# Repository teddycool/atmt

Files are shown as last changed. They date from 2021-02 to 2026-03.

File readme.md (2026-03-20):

# An Autonomous Toy Monster Truck

This project is undergoing a huge change and will be updated with new information and code. The project is now being prepared for ScaniaHack 2026 and use the progress we made in 2024 and 2025 as a starting point.

The old branches are still available and can be used for reference but the scaniahack2026 branch will be uppdated and restructured and then merged back to main when the hack is over.

## Repo Overview
The goal with this repo was to make an 'autonomous' toy-monster-truck, using my own electronic design and software for the control system. To get a head-start I used a cheap radio-controlled toy-truck and replaced the radio-control-pcb with my own designed control-system-pcb.

The 'brain' of the truck is an ESP32-wroom 8MB and the sensors used are ultrasonic distance-sensors and acc/gyro/compass. This design was made to be simple and easy to both understand and replicate. I hope it will be a source of inspiration and give ideas for improvements. 

I now have 2 of these trucks and I am planning to use them for ScaniaHack 2026.

This branch (ScaniaHack2026) is 'cleaned-up' and updated with alot of informatiom and will focus on the work at this years ScaniaHack 19th and 20th of March.

## ScaniaHack 2026 goal (only software)
We will use the 2 toy-trucks to build a cooperative, learning-based autonomous 'racing' system. The trucks will explore, map, optimize speed, and avoid obstacles on a simple bounded track.

By using the data collected from the trucks, we will implement a learning-based algorithm to optimize the racing strategy. The trucks will communicate with a backend server to share information about the track and their performance. The backend server(s) will also be responsible for storing the data and providing insights into the performance of the trucks.

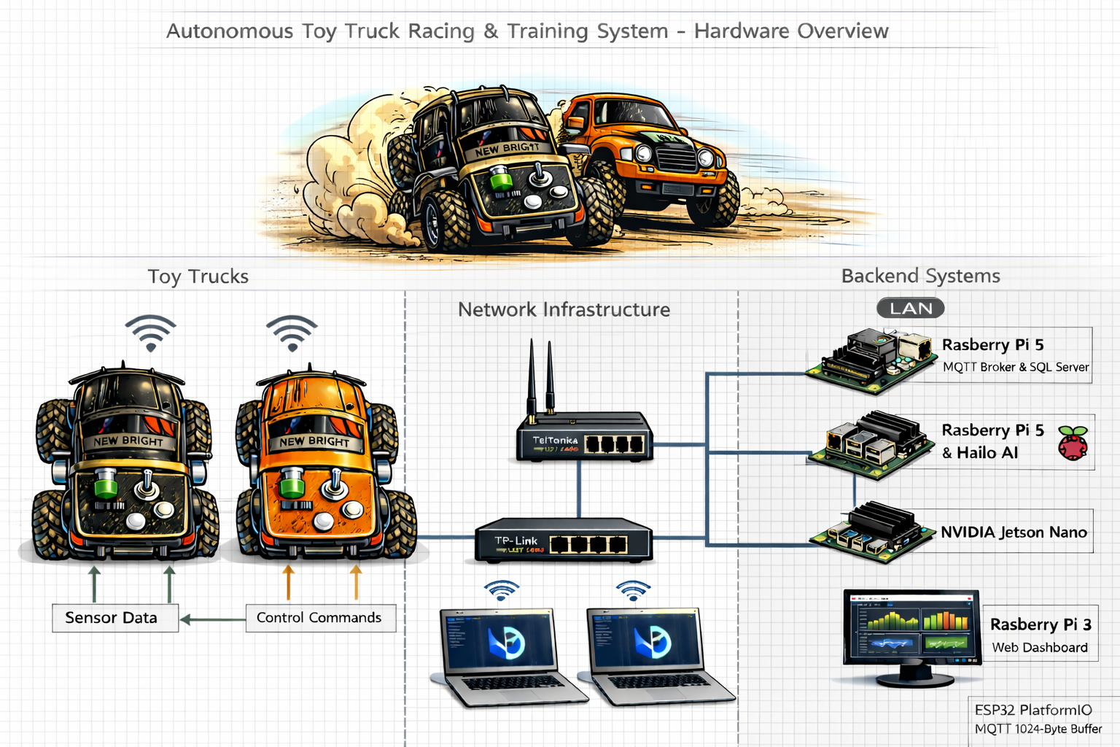
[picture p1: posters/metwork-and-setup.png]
The ScaniaHack 2026 setup


Link to the complete project description for ScaniaHack 2026: [ScaniaHack 2026 project description](ESP32_Truck_Hackathon_Project_Description.md)

### The simple track
Built with 45x70mm wood-planks, the track is a closed loop with angled corners and a clear start/finish line (the narrowest part).

### What we have
* 2 working toy-trucks with the same hardware setup and with 'ota' capabilities
* Backend servers for data collection, analysis and training of the learning-based algorithm
* A simple track for testing and racing
* Software components for sensors, basic control, data collection, and communication with the backend servers
* A dedicated server showing a dashboard with the telemetry

### What we need to implement
* An updated control-loop that 'explores' the track
* A backend 'training' that use the telemetry data to figure out the track geometry
* An updated control-loop that uses the information from backend to 'race' the track and improve laptimes

---

## How to contribute (not only code or ScaniaHack 2026) 

(More details for the git-magic in the wiki)

* Fork this repo from main and do your thing in a feature-branch from this fork on your own github-account 
* When done, make a pull-request back to main and describe your changes in the pull-request
* Try to keep one feature or bug-fix per pull-request to make the merging easier
* If you have any questions or need help, just ask me by pm, email, IRL or in the pull-request and I will try to help you out.

**Note: when working in vscode with platformio you need to open the EmbeddedSw subfolder from where you have cloned the repo, and then you can work, build and download to esp from there.**

## How to get started

[How to get started with coding](getstarted.md)

[HW schematics for reference](toy-truck/electronics/atmt-schematic-v3.pdf)

[Used hardware](toy-truck/electronics/hardware.md)

## Documentation

* [**Complete Project Description**](ESP32_Truck_Hackathon_Project_Description.md) - Comprehensive ScaniaHack 2026 project overview
* [Arduino OTA Process Guide](arduino-ota-process.md) - Complete guide for wireless firmware updates
* [Kalman Filter Implementation](kalman_filter.md) - Sensor fusion and filtering algorithms
* [EmbeddedSw Documentation](EmbeddedSw/README.md) - Main firmware documentation
* [Dashboard Setup](truck_telemetry_dashboard/README.md) - Real-time telemetry dashboard
* [Remote Control Guide](remote/README.md) - Manual and AI-based remote control

## Repo layout:

Current repository structure and components:

**Main Documentation (Root Level):**
* **ESP32_Truck_Hackathon_Project_Description.md** - Complete ScaniaHack 2026 project overview
* **arduino-ota-process.md** - Complete guide for Over-The-Air firmware updates
* **kalman_filter.md** - Implementation guide for sensor fusion algorithms

**Core Directories:**
* **EmbeddedSw/** - Main ESP32 firmware (PlatformIO project) - open this folder in VS Code to work with the truck control code
* **toy-truck/** - Hardware design and mechanical components
  * **electronics/** - PCB schematics (KiCAD), component lists, and hardware documentation
  * **Chassi-prep/** - CAD models and 3D printables for truck modifications
* **truck_telemetry_dashboard/** - Real-time web dashboard for monitoring truck telemetry data
* **remote/** - Manual control scripts and computer vision detection for remote operation
* **www/** - Backend web server components
  * PHP scripts for data logging and viewing
  * Database interaction utilities

**Supporting Materials:**
* **doc/** - Project documentation, system diagrams, and reference images
  * Architecture diagrams and project planning materials
  * Phase 1 mapping documentation
  * Historical work descriptions and conversion notes
* **posters/** - Visual presentation materials and setup diagrams for ScaniaHack 2026

---

## Other uses of this repo:
It is possible to use my PCB-design for an other type of vehicle or use the schematics and build any other sort of control-board. The ESP32 is a very versatile microcontroller and can be used for many different applications.

## Good links to get started with ESP32

* [Random Nerd Tutorials](https://randomnerdtutorials.com)
* [Espressif Resources](https://www.espressif.com/en/products/socs/esp32/resources)
* [ESP-IDF Programming Guide](https://docs.espressif.com/projects/esp-idf/en/latest/esp32/get-started/index.html)
* [Arduino Guide for ESP32](https://www.arduino.cc/en/Guide/ESP32)

## Connect and download to the ESP32

Connecting and downloading to the ESP might be a nightmare some times. Usually it goes well but when it starts to bug it can go on forever. However, you are not alone, google will help out when you search for your error message. 

Sometimes it works better if you power the pcb from the usb-port using a 3.3V type of FTD like FTDI1232 set to 3.3V. In this case the power from the batteries needs to be off or you might destroy the circuit. **Always leave battery-power off when using power from the programming interface**.

## Errata HW version 3 (important stuff)

* Some connections where missing in the first version of the schematics, like the connection between the B+ and the diode in the voltage-regulator. This is now fixed in the schematics and the pcb-layout for version 3.1

## Errata HW version 2 (important stuff)

* To keep the ESP safe on the io-side I am using rechargable batteries summing up to 3.6 volts which works just fine, but with alkalines you will probably get like 4.6 or 4.7 volts with fresh batteries which might damage the ESP32 io. Don't use those... 
* In the schematics I used a 1N4148 diode for reversed polarity protection but this was NOT a good choice. This can be left out completely or replaced by a schottky type of diode with a low voltage-drop.

## Starting material from Biltema's toy-department

Unfurthunatly this specific model is not sold anymore at Biltema but there are many other models at Biltema or elsewhere that can be used for this project. The most important thing is that the chassi is big enough to fit the new electronics and that the wheels are big enough to handle the terrain where you want to drive.

## Designing a new PCB formfactor

You can of course also design a new PCB formfactor from the schematics provided. The KiCAD files in the `toy-truck/electronics` directory include all the necessary components and connections. Feel free to modify the layout to better fit your specific needs or to improve the design. If you come up with a better design, please share it with the community by making a pull-request.

[Schematics for reference](toy-truck/electronics/atmt-schematic-v3.pdf)

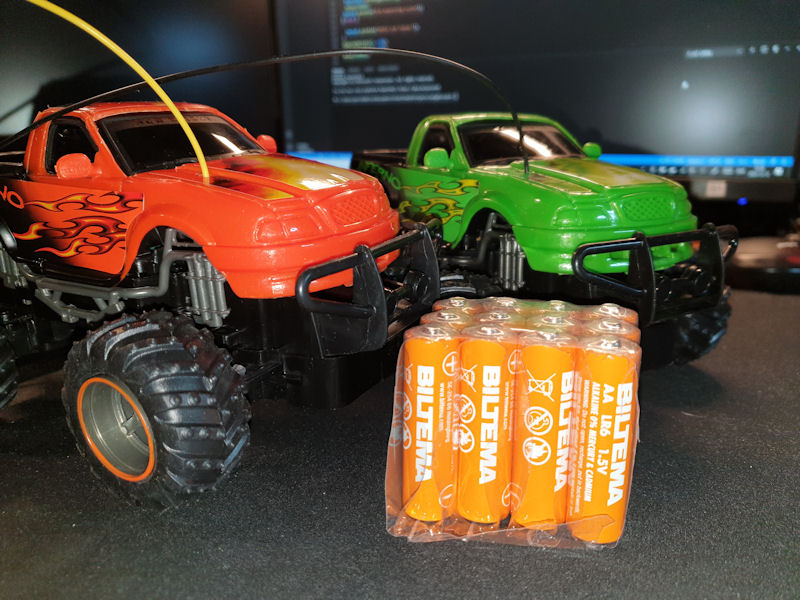
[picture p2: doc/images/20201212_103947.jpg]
Starters from Biltema toy-department


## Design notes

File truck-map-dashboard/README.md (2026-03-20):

# Truck Mapping Dashboard

A real-time web-based dashboard for mapping and tracking an autonomous toy truck. This is **Step 1** of a mapping system that receives telemetry from a truck and creates a live 2D occupancy grid map.

## Features

- **Real-time telemetry processing**: Receives truck sensor data via HTTP POST
- **Live pose estimation**: Tracks truck position and heading using motion model
- **Occupancy grid mapping**: Creates 2D maps using ultrasonic sensor data
- **Web dashboard**: Live-updating browser interface with WebSocket
- **SQLite logging**: Stores all telemetry data for analysis
- **Test mode**: Includes telemetry simulator for testing without real hardware

## Tech Stack

- **Python 3.11+**
- **Flask** - Web framework
- **Flask-SocketIO** - Real-time communication
- **NumPy** - Numerical computation for mapping
- **Pillow** - Image rendering
- **SQLite** - Data storage
- **eventlet** - Async support

## Project Structure

```
truck-map-dashboard/
├── app.py                 # Main Flask application
├── config.py             # Configuration settings
├── requirements.txt      # Python dependencies
├── telemetry_sim.py      # Test data generator
├── README.md             # This file
├── templates/
│   └── index.html        # Web dashboard UI
├── static/
│   └── style.css         # Dashboard styling
└── core/                 # Core mapping modules
    ├── telemetry.py      # Telemetry data handling
    ├── pose.py           # Pose estimation
    ├── occupancy_grid.py # Occupancy grid mapping
    ├── renderer.py       # Map visualization
    └── database.py       # SQLite operations
```

## Quick Start

### 1. Setup Python Environment

In VS Code, open a terminal and create a virtual environment:

```bash
# Navigate to project directory
cd truck-map-dashboard

# Create virtual environment
python3 -m venv venv

# Activate virtual environment
source venv/bin/activate  # On Linux/Mac
# or
venv\Scripts\activate     # On Windows
```

### 2. Install Dependencies

```bash
pip install -r requirements.txt
```

### 3. Run the Dashboard

```bash
python app.py
```

The dashboard will start at: **http://localhost:5000**

### 4. Test with Simulator

In a new terminal (with the virtual environment activated):

```bash
python telemetry_sim.py
```

This will generate fake truck telemetry and you should see the map updating in real-time!

## Usage

### Dashboard Interface

The web dashboard shows:

- **Live Map**: Real-time occupancy grid with truck position and heading
- **Truck Status**: Current position, heading, mode, and control commands  
- **Sensor Readings**: Ultrasonic sensor values (front, back, left, right)
- **System Stats**: Packet counts, map statistics, error counts
- **Controls**: Reset map, export PNG, view debug info

### API Endpoints

- `POST /api/telemetry` - Receive telemetry data
- `GET /api/status` - Get system status
- `GET /api/map/image` - Get current map as base64 PNG
- `POST /api/map/reset` - Reset map to empty state
- `POST /api/map/export` - Export map as PNG file
- `GET /api/debug` - Get detailed debug information

### Telemetry Format

Send JSON data to `/api/telemetry` with this structure:

```json
{
  "truck_id": "8a0a8ab4",
  "seq": 3282,
  "t_ms": 1876933,
  "free_heap": 216128,
  "mode": "RECOVER",
  "ul": 199.0,
  "ur": 199.0, 
  "uf": 18.0,
  "ub": 53.2,
  "yaw_rate": 1.88,
  "gy_x": -22.95,
  "gy_y": 23.25,
  "gy_z": 246.69,
  "heading": 144.3,
  "compass": 144.3,
  "mag_x": 10.00,
  "mag_y": 11.00,
  "mag_z": -36.02,
  "acc_x": -143.58,
  "acc_y": 4390.02,
  "acc_z": 15981.24,
  "width": 398.0,
  "center_error": -0.0,
  "front_blocked": true,
  "cmd_pwm": 95,
  "cmd_steer": "LEFT"
}
```

## Configuration

Edit `config.py` to tune the mapping system:

### Motion Model
```python
SPEED_PER_PWM = 0.005       # Speed in m/s per PWM unit
MAX_SPEED_MPS = 0.5         # Maximum speed 
TURN_SPEED_FACTOR = 0.3     # Speed reduction while turning
```

### Map Settings
```python
MAP_WIDTH_M = 10.0          # Map width in meters
MAP_HEIGHT_M = 10.0         # Map height in meters  
CELL_SIZE_M = 0.05          # Resolution: 5cm per cell
```

### Sensor Model
```python
SENSOR_MAX_RANGE_CM = 180.0 # Maximum trusted range
SENSOR_MIN_RANGE_CM = 2.0   # Minimum trusted range
SENSOR_INVALID_VALUE = 199.0 # Value for "no return"
```

## How It Works

### 1. Telemetry Processing
- Validates incoming JSON packets
- Parses sensor readings and control commands
- Stores raw data in SQLite database

### 2. Pose Estimation
- Uses heading from compass/IMU as primary orientation
- Estimates forward motion from PWM commands and time
- Applies speed reductions for turning and recovery modes
- Maintains (x, y, θ) pose estimate

### 3. Occupancy Grid Mapping
- Creates 2D grid with configurable resolution (default: 5cm cells)
- Uses log-odds representation for occupancy probabilities
- For each ultrasonic sensor:
  - Traces ray from sensor to detected obstacle
  - Marks free space along ray
  - Marks endpoint as occupied (if valid reading)
- Handles sensor placement and orientation relative to truck

### 4. Visualization
- Renders occupancy grid as grayscale image
- Overlays truck position (red circle) and heading (red line)
- Shows coordinate system and scale information
- Updates in real-time via WebSocket

## Limitations (Step 1)

This is a basic mapping system with these limitations:

- **No SLAM**: No loop closure or scan matching
- **Simple motion model**: Basic PWM-to-speed conversion
- **No sensor fusion**: Relies primarily on heading sensor
- **No obstacle tracking**: Static occupancy representation
- **Limited sensor model**: Simple ray-casting model

## Next Steps

Future improvements could include:

1. **Scan matching** for improved pose accuracy
2. **Loop closure detection** for map consistency  
3. **Kalman filtering** for sensor fusion
4. **Dynamic obstacle tracking**
5. **Path planning integration**
6. **Camera data processing** with Hailo acceleration

## Troubleshooting

### Dashboard won't load
- Check if Flask app is running: `python app.py`
- Verify port 5000 is not in use
- Check browser console for JavaScript errors

### Simulator not connecting
- Ensure Flask app is running first
- Check firewall/network settings
- Verify URL in telemetry_sim.py matches Flask server

### Map not updating
- Check WebSocket connection status in browser
- Verify telemetry data format matches expected JSON
- Check browser developer tools for errors
- Look at Flask console output for error messages

### Tuning the motion model
- Adjust `SPEED_PER_PWM` in config.py based on your truck's speed
- Modify `TURN_SPEED_FACTOR` if turning behavior looks wrong
- Change `SENSOR_MAX_RANGE_CM` to match your sensor specifications

### Performance issues
- Reduce map size or increase cell size for better performance
- Lower telemetry update rate if CPU usage is high
- Check available RAM for large maps

## Development

### Adding new features
1. Core mapping logic goes in the `core/` modules
2. Web API endpoints are added to `app.py`
3. UI updates go in `templates/index.html` and `static/style.css`
4. Configuration options are defined in `config.py`

### Testing
- Use `telemetry_sim.py` for development testing
- Modify simulator parameters to test edge cases
- Export maps as PNG for visual verification
- Check debug endpoint for detailed state information

---

**Happy Mapping! 🗺️🚛**

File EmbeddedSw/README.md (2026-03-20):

# Autonomous Truck Control System

A real-time ESP32-based autonomous truck control system with sensor fusion, state machine control, and telemetry integration for warehouse/industrial navigation.

## 🚛 System Overview

This system implements an autonomous truck capable of:
- **Autonomous Navigation**: Wall-following and corridor-centering using ultrasonic sensors
- **Obstacle Avoidance**: Real-time collision detection and recovery maneuvers
- **State Management**: Robust state machine with IDLE/EXPLORE/RECOVER/STOP modes
- **Real-time Telemetry**: 1Hz MQTT telemetry with sensor data and control state
- **Remote Monitoring**: Web dashboard for live visualization and control

## 🏗️ Architecture

```
┌─────────────────┐    ┌──────────────────┐    ┌─────────────────┐
│   ESP32 Truck   │◄──►│  MQTT Broker     │◄──►│ Flask Dashboard │
│                 │    │ (192.168.2.2)    │    │ (WebSocket)     │
│ ┌─────────────┐ │    │                  │    │                 │
│ │Control Loop │ │    │ Topics:          │    │ - Live Sensors  │
│ │   1Hz       │ │    │ {chipId}/sensors │    │ - State Viz     │
│ │             │ │    │ {chipId}/control │    │ - Controls      │
│ └─────────────┘ │    │ {chipId}/config  │    │                 │
│                 │    └──────────────────┘    └─────────────────┘
│ Sensors:        │
│ - 4x Ultrasonic │
│ - MPU6050       │
│ - Magnetometer  │
│                 │
│ Actuators:      │
│ - Motor Control │
│ - Steering      │
└─────────────────┘
```

## 📁 Project Structure

```
EmbeddedSw/
├── src/
│   ├── z_main_control_loop.cpp     # Main control loop
│   ├── z_main_wifi_test.cpp        # Network connectivity test
│   ├── z_main_minimal_test.cpp     # Hardware recovery utility
│   ├── config.cpp                  # Hardware configuration
│   ├── secrets.cpp                 # WiFi credentials
│   ├── actuators/
│   │   ├── motor.cpp               # Motor PWM control
│   │   ├── steer.cpp               # Steering control
│   │   ├── neopixel.cpp            # LED indicators (optional)
│   │   └── light.cpp               # Light control (optional)
│   ├── sensors/
│   │   ├── accsensor.cpp           # MPU6050 accelerometer/gyro
│   │   ├── compass.cpp             # Magnetometer with Kalman filtering
│   │   ├── usensor.cpp             # Ultrasonic sensor array
│   │   └── kalman_filter.cpp       # Kalman filter implementation
│   ├── telemetry/
│   │   ├── mqtt.cpp                # MQTT communication
│   │   └── logger.cpp              # HTTP logging (optional)
│   └── variables/
│       └── setget.cpp              # Thread-safe global variables
├── include/                        # Header files
├── platformio.ini                  # Build configuration
└── truck_telemetry_dashboard/      # Python Flask dashboard
    ├── app.py                      # WebSocket server
    ├── templates/index.html        # Web interface
    └── requirements.txt            # Python dependencies
```

## 🎛️ Control Loop Architecture

### State Machine

The control loop operates as a finite state machine with four primary states:

```cpp
enum class Mode {
    IDLE,       // Stationary, awaiting commands
    EXPLORE,    // Active navigation with wall-following
    RECOVER,    // Obstacle avoidance maneuvers
    STOP        // Emergency stop condition
};
```

### Sensor Fusion Pipeline

#### 1. Ultrasonic Sensor Array
```cpp
struct UltrasonicReadings {
    float ul;  // Upper left  (45°)
    float ur;  // Upper right (45°) 
    float sl;  // Side left   (90°)
    float sr;  // Side right  (90°)
};
```

#### 2. IMU Processing
- **MPU6050**: Raw accelerometer (±2g) and gyroscope (±250°/s)
- **EMA Filtering**: Configurable smoothing (α = 0.1 default)
- **Compass**: HMC5883L with Kalman filtering for magnetic interference

#### 3. Feature Extraction
```cpp
struct Features {
    float width;        // Corridor width (ul + ur)
    float centerError;  // Distance from corridor center
    float frontDist;    // Minimum forward obstacle distance
    float sideDist;     // Minimum side clearance
};
```

### Control Algorithm

#### Wall-Following Logic
```cpp
// Corridor centering with configurable gains
float steerGain = 2.0f;       // Proportional steering response
float centerTarget = 0.0f;    // Desired center position
float steerCmd = steerGain * (centerTarget - centerError);
```

#### State Transitions
- **IDLE → EXPLORE**: Manual command or timer trigger
- **EXPLORE → RECOVER**: Front obstacle detected (`frontDist < stopDist`)
- **RECOVER → EXPLORE**: Clear path restored
- **ANY → STOP**: Emergency condition or manual override

#### Safety Parameters
```cpp
float stopDist = 15.0f;      // Emergency stop distance (cm)
float sideMinDist = 6.0f;    // Minimum side clearance (cm)
float maxSpeed = 150;        // Maximum motor PWM (0-255)
```

## 📡 Communication Protocol

### MQTT Topics

All topics are prefixed with unique `chipId` (ESP32 MAC-derived):

#### Telemetry (Outbound - 1Hz)
```
{chipId}/sensors
```

**Payload Structure:**
```json
{
  "truck_id": "abc123def456",
  "seq": 1234,
  "timestamp": 1734567890,
  "mode": "EXPLORE",
  "sensors": {
    "ul": 25.4, "ur": 23.8, "sl": 12.3, "sr": 15.7,
    "accX": 0.12, "accY": -0.05, "accZ": 9.81,
    "gyroZ": 2.3, "compass": 185.7
  },
  "features": {
    "width": 49.2,
    "centerError": -1.4,
    "frontDist": 45.6,
    "sideDist": 12.3
  },
  "control": {
    "motorPwm": 120,
    "steerCmd": "RIGHT",
    "steerPwm": 85
  }
}
```

#### Control Commands (Inbound)
```
{chipId}/control
```

**Supported Commands:**
```json
{"command": "start"}        // IDLE → EXPLORE
{"command": "stop"}         // ANY → STOP  
{"command": "emergency"}    // Immediate halt
```

#### Configuration (Inbound)
```
{chipId}/config
```

**Runtime Parameters:**
```json
{
  "stopDist": 15.0,
  "steerGain": 2.0,
  "maxSpeed": 150,
  "emaAlpha": 0.1
}
```

## 🛠️ Development Setup

### Prerequisites
- **PlatformIO** (VS Code extension recommended)
- **Python 3.8+** (for dashboard)
- **ESP32 Development Board**
- **MQTT Broker** (Mosquitto recommended)

### Hardware Configuration

#### Required Sensors
- **4x HC-SR04** ultrasonic sensors (trigger/echo pairs)
- **MPU6050** accelerometer/gyroscope (I2C)
- **HMC5883L** magnetometer (I2C)

#### Pin Assignments (see `include/atmio.h`)
```cpp
// Ultrasonic sensors
#define TRIG_PIN_UL  2   // Upper left trigger
#define ECHO_PIN_UL  4   // Upper left echo
// ... additional sensor pins

// Motor control  
#define MOTOR_PWM_PIN    5
#define MOTOR_DIR_PIN    18

// Steering
#define STEER_PWM_PIN    19
#define STEER_DIR_PIN    21
```

### Building and Flashing

1. **Configure WiFi credentials** in `src/secrets.cpp`
2. **Build control loop**:
   ```bash
   pio run -e control_loop
   ```
3. **Flash firmware**:
   ```bash
   pio run -e control_loop --target upload
   ```
4. **Monitor serial output**:
   ```bash
   pio device monitor -e control_loop
   ```

### Dashboard Setup

1. **Install Python dependencies**:
   ```bash
   cd truck_telemetry_dashboard
   pip install -r requirements.txt
   ```

2. **Start dashboard**:
   ```bash
   ./start_dashboard.sh
   ```

3. **Access interface**: http://localhost:5000

## 🧪 Testing Utilities

### WiFi Connectivity Test
```bash
pio run -e wifi_test --target upload
```
Validates network connection and MQTT broker connectivity.

### Minimal Hardware Test  
```bash
pio run -e minimal_test --target upload
```
Basic GPIO/sensor validation - useful for hardware debugging.

### Recovery Mode
If ESP32 becomes unresponsive, flash `minimal_test` to restore basic functionality.

## 🔧 Configuration

### Compile-time Configuration (`include/config.h`)
```cpp
motorType = SINGLE;          // Motor configuration
steerType = MOTOR;           // Steering type (MOTOR/SERVO)
steer_servo_min = 60;        // Minimum steering PWM
steer_servo_max = 105;       // Maximum steering PWM
```

### Runtime Parameters (via MQTT)
- **Safety distances**: `stopDist`, `sideMinDist`
- **Control gains**: `steerGain`, `maxSpeed`
- **Filter coefficients**: `emaAlpha`

## 🚀 Adding New Features

### New Sensor Integration
1. **Add sensor class** in `src/sensors/`
2. **Define header** in `include/sensors/`
3. **Update telemetry structure** in `z_main_control_loop.cpp`
4. **Add to build filter** in `platformio.ini`

### Custom Control Modes
1. **Extend Mode enum** in control loop
2. **Implement state logic** in main switch statement
3. **Add transition conditions**
4. **Update telemetry reporting**

### MQTT Command Extensions
1. **Parse new commands** in `mqttCallback()`
2. **Implement command handlers**
3. **Update dashboard controls**
4. **Document protocol changes**

## ⚡ Performance Characteristics

- **Control Loop Frequency**: 1Hz (memory-optimized for stability)
- **Sensor Reading Rate**: ~10Hz internal, 1Hz telemetry
- **MQTT Latency**: <50ms typical
- **Memory Usage**: 
  - RAM: ~45KB (13.7% of 328KB)
  - Flash: ~790KB (60% of 1.3MB)

## 🛡️ Safety Features

- **Watchdog timer**: Auto-restart on system hang
- **Emergency stop**: Immediate motor shutoff via MQTT
- **Collision detection**: Multi-sensor obstacle avoidance
- **Recovery sequences**: Automated backup/turn maneuvers
- **Telemetry validation**: Sensor health monitoring

## 📊 Monitoring and Debugging

### Serial Output
Real-time debug information at 115200 baud:
- Sensor readings and filtered values
- State transitions and control decisions
- MQTT connection status and message handling
- Performance metrics and timing

### Dashboard Visualization
- Live sensor data with time-series plots
- State machine visualization
- Manual control interface
- System health indicators

---

## 📝 License

This project is developed for research and educational purposes. See project documentation for specific licensing terms.

## 🤝 Contributing

1. **Fork** the repository
2. **Create feature branch** (`git checkout -b feature/new-capability`)
3. **Test thoroughly** with hardware-in-the-loop
4. **Submit pull request** with comprehensive description

For questions or support, consult the project documentation or create an issue in the repository.

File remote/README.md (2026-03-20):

# Remote Control and Computer Vision

This directory contains remote control capabilities for the autonomous trucks, including manual control scripts and computer vision-based steering.

## Components

### 1. Manual Remote Control (`remote.py`, `remote.sh`)

Scripts for manual control of the trucks via MQTT commands.

**Usage:**
```bash
python3 remote.py
# or
./remote.sh
```

Control with keyboard:
- **W**: Move forward
- **A**: Turn left
- **D**: Turn right
- **S**: Move backward/stop

### 2. Computer Vision Detection (`remote_image_detection.py`)

YOLO-based object detection system that can automatically steer the truck based on visual input.

**Setup:**
1. Create a virtual environment:
   ```bash
   python3 -m venv yolo_env
   source yolo_env/bin/activate  # Linux/Mac
   # or
   yolo_env\Scripts\activate     # Windows
   ```

2. Install dependencies:
   ```bash
   pip install -r requirements.txt
   ```

3. Run the detection system:
   ```bash
   python3 remote_image_detection.py
   ```

**Features:**
- Object detection using YOLOv8n model
- Real-time steering commands via MQTT
- Configurable for different truck ESP32 IDs

### 3. Bash Remote Control (`bash_remote_control/`)

Alternative bash-based remote control scripts:
- `detection_script.py`: Computer vision detection
- `remote_json.sh`: JSON-based MQTT commands
- `remote.sh`: Simple control interface

## Configuration

Make sure to update the ESP32 chip ID in the scripts to match your truck:
- Check the serial output from your ESP32 for the chip ID
- Update the topic name in the scripts (format: `{chipId}/control`)

## MQTT Topics

The remote control uses these MQTT topics:
- **Control commands**: `{chipId}/control`
- **Telemetry data**: `{chipId}/sensors`

## Network Requirements

- Same WiFi network as the trucks
- MQTT broker accessible at configured IP (usually 192.168.2.2)
- Python 3.8+ for computer vision features

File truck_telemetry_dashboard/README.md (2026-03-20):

# 🚛 Autonomous Truck Telemetry Dashboard

A real-time web dashboard for monitoring autonomous truck telemetry data via MQTT. Built with Flask and SocketIO for live updates.





## Features

- 🔴 **Real-time telemetry display** - Live updates via WebSockets
- 📡 **MQTT Integration** - Connects to truck's MQTT broker
- 📊 **Visual sensor layout** - Intuitive ultrasonic sensor positioning
- 🎮 **Control monitoring** - Motor PWM and steering commands
- 🧭 **Navigation data** - Corridor centering and heading information
- 📈 **Telemetry history** - Recent message log with timestamps
- 📱 **Responsive design** - Works on mobile devices and tablets

## Installation

### On Raspberry Pi 5

1. **Clone/Copy the dashboard files:**
   ```bash
   cd /home/pi
   # Copy the truck_telemetry_dashboard directory here
   ```

2. **Create Python virtual environment:**
   ```bash
   cd truck_telemetry_dashboard
   python3 -m venv dashboard_env
   source dashboard_env/bin/activate
   ```

3. **Install Python dependencies:**
   ```bash
   pip install -r requirements.txt
   ```

4. **Update MQTT broker IP (if needed):**
   ```bash
   nano app.py
   # Change MQTT_BROKER = "192.168.2.2" to your broker IP
   ```

### Easy Setup (Recommended)

Just use the provided launch script:
```bash
./start_dashboard.sh
```

## Development Mode

For layout development and testing without real trucks or MQTT infrastructure, use the development mode:

### 🔧 Development Dashboard Setup

The development mode provides:
- **Mock telemetry data** - Realistic sensor data generated locally  
- **No MQTT dependency** - Works without network infrastructure
- **Faster iteration** - Perfect for layout and UI development
- **Multiple truck simulation** - Tests multi-truck display

#### Quick Start (Development)
```bash
cd truck_telemetry_dashboard
./start_dev.sh
```

Or manually:
```bash
cd truck_telemetry_dashboard
python3 -m venv dashboard_env
source dashboard_env/bin/activate
pip install flask
python3 dashboard_dev.py
```

The development dashboard will be available at **http://localhost:5001**

#### Development vs Production
| Feature | Development | Production |
|---|---|---|
| **Data Source** | Mock/Random | Real MQTT |
| **Network** | None required | MQTT Broker |
| **Trucks** | 2 simulated | Real hardware |
| **Updates** | 1Hz fixed | 1Hz throttled |
| **Use Case** | Layout/UI work | Live monitoring |
cd truck_telemetry_dashboard
chmod +x start_dashboard.sh
./start_dashboard.sh
```

The script will automatically:
- Create virtual environment if needed
- Install dependencies
- Check MQTT broker connectivity  
- Start the dashboard

## Usage

### Start the Dashboard

```bash
cd truck_telemetry_dashboard
python3 app.py
```

### Access the Dashboard

- **Local access:** http://localhost:5000
- **Network access:** http://[PI_IP_ADDRESS]:5000
- **From any device on network:** http://192.168.2.X:5000

### Auto-start on Boot (Raspberry Pi)

Create a systemd service:

```bash
sudo nano /etc/systemd/system/truck-dashboard.service
```

Add this content:
```ini
[Unit]
Description=Truck Telemetry Dashboard
After=network.target

[Service]
Type=simple
User=pi
WorkingDirectory=/home/pi/truck_telemetry_dashboard
ExecStart=/usr/bin/python3 app.py
Restart=always

[Install]
WantedBy=multi-user.target
```

Enable and start:
```bash
sudo systemctl enable truck-dashboard.service
sudo systemctl start truck-dashboard.service
```

## Configuration

### MQTT Settings (in app.py)

```python
MQTT_BROKER = "192.168.2.2"    # Your MQTT broker IP
MQTT_PORT = 1883               # MQTT broker port
MQTT_TOPIC = "telemetry"       # Topic truck publishes to
```

### Web Server Settings

```python
host='0.0.0.0'    # Listen on all interfaces
port=5000         # Web server port
debug=False       # Set True for development
```

## Telemetry Data Format

The dashboard expects JSON telemetry in this format:

```json
{
  "truck_id": "b4328a0a8ab4",
  "seq": 123,
  "t_ms": 45670,
  "mode": "EXPLORE", 
  "ul": 45.2,         // Ultrasonic left (cm)
  "ur": 38.7,         // Ultrasonic right (cm)  
  "uf": 67.1,         // Ultrasonic front (cm)
  "ub": 42.3,         // Ultrasonic back (cm)
  "yaw_rate": 1.23,   // Gyro yaw rate (deg/s)
  "heading": 0.0,     // Compass heading (deg)
  "width": 83.9,      // Corridor width (cm)
  "center_error": -6.5, // Center error (cm)
  "front_blocked": false,
  "cmd_pwm": 70,      // Motor PWM command
  "cmd_steer": "LEFT" // Steering command
}
```

## API Endpoints

- `GET /` - Main dashboard page
- `GET /api/status` - System status JSON
- `GET /api/telemetry` - Latest telemetry JSON
- `GET /api/history` - Telemetry history JSON

## Troubleshooting

### MQTT Connection Issues

1. **Check broker IP:** Ensure MQTT_BROKER matches your setup
2. **Network connectivity:** `ping 192.168.2.2` from Pi
3. **Firewall:** Ensure port 1883 is accessible
4. **Broker status:** Check MQTT broker is running

### Web Access Issues

1. **Port binding:** Ensure port 5000 is not in use
2. **Firewall:** Check Pi firewall allows port 5000
3. **Network:** Ensure Pi is on same network as accessing device

### Service Logs

```bash
sudo journalctl -u truck-dashboard.service -f
```

## Development

### Local Development

```bash
# Install dependencies
pip3 install -r requirements.txt

# Run with debug enabled
python3 app.py
```

Set `debug=True` in app.py for development mode with auto-reload.

### File Structure

```
truck_telemetry_dashboard/
├── app.py              # Main Flask application
├── requirements.txt    # Python dependencies  
├── README.md          # This file
├── templates/
│   └── index.html     # Dashboard HTML template
└── static/
    └── style.css      # Dashboard styling
```

## System Requirements

- **Python 3.8+**
- **Raspberry Pi 5** (or any Linux system)
- **Network access** to MQTT broker
- **Web browser** supporting WebSockets

## License

MIT License - See LICENSE file for details.

## Support

For issues or questions:
1. Check the troubleshooting section
2. Verify MQTT broker connectivity
3. Check system logs for errors

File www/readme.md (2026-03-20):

# Backend files

The server is located at 192.168.2.2 in the local HackNet1.

Instructions for mounting fileshares in linux at http://192.168.2.2/

## The database tables
<!-- image:db-tables.png[] -->

## post_log.php
Inserts data to the logging table

http://192.168.2.2/post_log.php?chipid=123&msg=LogMessage

## post_value.php
Inserts data to the Measurment table

http://192.168.2.2/post_value.php?chipid=123&name=distr&value=32.5&unit=cm

## scaniahack-db-exp.sql

A dump of the databse structure and some content in the logging table.

## TBD
Add scripts for filtering and viewing of logs and measurements

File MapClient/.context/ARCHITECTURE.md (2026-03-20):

# Architecture

## Overview
Python tooling for simulating and visualising autonomous toy truck navigation.
Companion to the ESP32 firmware in `EmbeddedSw/`.

## Components

### truck_simulator.py
- Simulates one or more trucks in a 2-D field and publishes telemetry via MQTT.
- **Field**: configurable width × height in cm (currently 120 × 240 cm).
- **Obstacles**: static axis-aligned rectangles defined in `OBSTACLES`.
- **Sensors**: 4 ultrasonic rays (front, back, left, right) with Gaussian noise.
- **Strategy pattern**: `ExploreStrategy` base class; concrete strategies plugged into `Truck`.
  - `ReactiveExplore`: simple turn-away-from-obstacle logic.
  - `EmbeddedExplore`: mirrors the ESP32 embedded control loop exactly (EMA filtering, corridor centering, hysteresis, timed recovery).
- **MQTT topic**: `{TRUCK_ID}/telemetry` (default `ESP32_TRUCK_SIM/telemetry`).

### map_visualization.py
- Subscribes to `+/telemetry` (wildcard) and discovers trucks dynamically.
- Dead-reckons position from `compass`/`heading` + `cmd_pwm` if `x`/`y` not in payload; uses ground-truth `x`/`y` when available (simulator).
- Projects sensor rays to collect wall-hit points.
- Fits an axis-aligned bounding rectangle to wall points (percentile-trimmed).
- Renders path, wall scatter, heading arrow, and estimated boundary in real time via matplotlib `FuncAnimation`.

## MQTT
- Broker: `192.168.2.2:1883` (configurable via `--broker`/`--port`).
- Topic pattern: `{truck_id}/telemetry`.
- Payload: JSON — see `docs/VARIABLE_MODEL.md` for field definitions.

## Key Decisions
- Modular strategy pattern chosen so embedded exploration logic can be simulated without changing the truck core.
- `EmbeddedExplore` keeps all strategy-specific state (filtered values, steer hysteresis, recovery timer) inside the strategy, not on `Truck`.
- Boundary inference uses percentile trimming (not min/max) to be robust to sensor noise outliers.

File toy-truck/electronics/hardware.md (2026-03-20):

# Used hardware components

The main hardware components with some references.

## ESP32 WROOM
ESP32-WROOM-32UE-N16

https://www.mouser.se/c/?q=ESP32-WROOM-32UE-N16

## Motor-control

L293D (SMD)

https://www.mouser.se/datasheet/2/389/l293d-1849134.pdf

## Ultrasonic sensor

HC-SR04 

User-guide: 
https://www.handsontec.com/dataspecs/HC-SR04-Ultrasonic.pdf

## Accelerometer/gyro

GY-521 

https://www.instructables.com/GY-521-MPU6050-3-Axis-Acceleration-Gyroscope-6DOF-/
https://randomnerdtutorials.com/arduino-mpu-6050-accelerometer-gyroscope/#more-101585

## Compass

GY-273

https://www.robotpark.com/GY-273-HMC5883L-3-Axis-Magnetic-Electronic-Compass

## Power-supply

3xAA and a 3.3 low dropout voltage regulator LP2989 (SMD) 

https://www.electrokit.com/upload/product/40352/40352989/LP2989.pdf

## Add-ons for HW version 3

* Support for a buck/boost regulator expansion-board, for a stable 5V (https://www.electrokit.com/switchregulator-step-up/step-down-5v-1a)
* TTL-CMOS level converter for the echo signal
* Analog voltage measurement for battery energy level
* Status-led/neopixel

## Material cost pcb HW version 2 with components (approx SEK, 2024 prices)

Around 300 SEK divided as:

* PCB (Aisler.net):  75
* ESP32 (mouser.se): 40
* L293 (mouser.se): 100
* LP2989 (electrokit.se): 60
* Pinheaders, smd-button, capacitors etc...

## Material cost pcb HW version 3 with components (approx SEK, 2024 prices)

Around 350 SEK divided as:

* PCB (Aisler.net):  75
* ESP32 (mouser.se): 40
* L293 (mouser.se): 100
* LP2989 (electrokit.se): 60
* Buck/boost regulator (electrokit.se): 50
* Level converter (electrokit.se): 20
* Pinheaders, smd-button, capacitors etc...

### Sensors etc

* 4*HC-SR04 (https://www.electrokit.com/avstandsmatare-ultraljud-hc-sr04-2-400cm)
* 1*GY-521 (https://www.electrokit.com/mpu-6050-accelerometer-3-axel-gyro-monterad-pa-kort)
* 1*GY-273 (https://www.electrokit.com/elektronisk-kompass-hmc5883l)
* 6*cables for the sensors (https://www.electrokit.com/labsladd-4-pin-100mm)

### Programming interface

Something like this: https://www.electrokit.com/beefy-3-ftdi-breakout with some cables like this to fit the connector on the pcb: https://www.electrokit.com/labbsladd-40-pin-30cm-hona/hane

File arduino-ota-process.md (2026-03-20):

# Arduino OTA (Over-The-Air) Update Process for ATMT Trucks

## Overview

The ATMT project uses Arduino OTA to wirelessly update firmware on ESP32-based trucks without requiring physical access to the devices. This document describes the current implementation and how to perform OTA updates.

## How OTA Works in ATMT

### 1. OTA Initialization

The OTA functionality is implemented in the main control loop (`z_main_control_loop.cpp`) and follows these steps:

1. **WiFi Connection**: Each truck connects to the configured WiFi network using credentials from `secrets.h`
2. **Hostname Setup**: Each truck gets a unique hostname: `truck-{chipId}` where chipId is derived from the ESP32's hardware
3. **OTA Configuration**: Arduino OTA is configured with authentication and callback handlers
4. **OTA Ready**: The system becomes ready to receive firmware updates

### 2. OTA Configuration Details

```cpp
// Hostname: truck-{unique_chip_id}
ArduinoOTA.setHostname(("truck-" + chipId).c_str());

// Fixed password for all trucks
ArduinoOTA.setPassword("truck123");
```

### 3. OTA Event Handlers

The system includes comprehensive error handling and progress monitoring:

- **onStart()**: Logs when update begins (sketch or filesystem)
- **onEnd()**: Confirms successful completion
- **onProgress()**: Shows percentage progress during upload
- **onError()**: Handles various error conditions:
  - Authentication failures
  - Connection issues
  - Upload errors
  - Begin/End errors

### 4. Runtime Operation

In the main control loop, `ArduinoOTA.handle()` is called continuously to:
- Listen for incoming OTA requests
- Process firmware uploads
- Handle authentication
- Manage the update process

## Performing an OTA Update

### Prerequisites

1. **Network Access**: Ensure you're on the same WiFi network as the trucks
2. **Arduino IDE**: Install Arduino IDE with ESP32 board support
3. **Source Code**: Have the updated firmware ready to compile

### Update Process

1. **Identify Target Truck**:
   - Each truck broadcasts its hostname: `truck-{chipId}`
   - Use network discovery tools or check serial output for the exact hostname

2. **Configure Arduino IDE**:
   - Open your project in Arduino IDE
   - Go to `Tools > Port`
   - Select the network port showing your target truck (e.g., `truck-abc123 at 192.168.1.100`)

3. **Upload Firmware**:
   - Click "Upload" or press `Ctrl+U`
   - Enter the OTA password: `truck123`
   - Monitor progress in the IDE console

4. **Verify Update**:
   - Check serial output for "OTA Update Complete!"
   - Verify the truck reboots and functions correctly
   - Confirm new functionality is working

### Alternative: Command Line Upload

You can also use `arduino-cli` or `platformio` for OTA uploads:

```bash
# Using platformio (if configured)
pio run -e control_loop --target upload --upload-port truck-{chipId}.local

# The system will prompt for the OTA password: truck123
```

## Network Requirements

### WiFi Configuration

- **SSID & Password**: Configured in `secrets.h`
- **Network Type**: 2.4GHz WiFi (ESP32 limitation)
- **Connectivity**: Trucks must maintain stable connection during update

### Firewall Considerations

- **Port 3232**: Arduino OTA default port (must be open)
- **mDNS**: Multicast DNS for hostname resolution
- **Local Network**: OTA only works on the same subnet

## Security Considerations

### Current Implementation

- **Fixed Password**: All trucks use the same OTA password (`truck123`)
- **Network Security**: Relies on WiFi network security
- **Plain Text**: Password is hardcoded in source code

### Recommendations

For production deployment, consider:

1. **Unique Passwords**: Generate unique OTA passwords per device
2. **Certificate-based Auth**: Implement certificate-based authentication
3. **Encrypted Updates**: Add firmware encryption
4. **Access Control**: Implement role-based access control

## Troubleshooting

### Common Issues

1. **Truck Not Found**:
   - Verify truck is connected to WiFi
   - Check hostname in serial output
   - Ensure same network subnet

2. **Authentication Failed**:
   - Verify password is `truck123`
   - Check for typos in password entry

3. **Upload Timeout**:
   - Ensure stable WiFi connection
   - Try again during low network activity
   - Check truck isn't in a control loop that blocks OTA handling

4. **Update Failed**:
   - Check available flash memory
   - Verify firmware size is within limits
   - Monitor serial output for specific error codes

### Debugging

Enable verbose output in Arduino IDE:
- `File > Preferences > Show verbose output during: upload`
- Check serial monitor for detailed error messages

## Code Structure

### Key Files

- **Main Loop**: `EmbeddedSw/src/z_main_control_loop.cpp`
  - OTA initialization (lines ~605-634)
  - OTA handling in main loop (line ~737)

- **Includes**: Required libraries
  - `#include <ArduinoOTA.h>`
  - `#include <WiFi.h>`

- **Dependencies**: PlatformIO automatically includes Arduino OTA library

### Integration Points

OTA is integrated at two main points:

1. **Setup Phase**: Initialize OTA after WiFi connection
2. **Main Loop**: Call `ArduinoOTA.handle()` regularly

This ensures OTA updates can be received and processed while the truck continues normal operation.

## Best Practices

1. **Stable WiFi**: Ensure strong WiFi signal before starting updates
2. **Backup Firmware**: Keep working firmware versions for rollback
3. **Test Updates**: Validate new firmware on a single truck first
4. **Scheduled Updates**: Perform updates during maintenance windows
5. **Monitor Progress**: Watch serial output and IDE progress during updates
6. **Version Control**: Use clear version numbering for firmware builds

## Limitations

- **Network Dependency**: Requires stable WiFi connection
- **Single Update**: One truck can be updated at a time per IDE instance
- **Flash Constraints**: Update size limited by available flash memory
- **Timing Sensitive**: Main loop must frequently call `ArduinoOTA.handle()`

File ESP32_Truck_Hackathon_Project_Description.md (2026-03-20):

# ESP32 Truck Hackathon Project Description
## ScaniaHack 2026 - Autonomous Racing System

### Project Overview

The **Autonomous Toy Monster Truck (ATMT)** this is a for ScaniaHack 2026, focusing on developing a cooperative, learning-based autonomous racing system using two ESP32-powered toy trucks.

### 🎯 Project Goals

**Primary Objective**: Build a cooperative autonomous racing system where trucks:
- Autonomously explore and map a bounded track
- Optimize racing strategies using collected data  
- Communicate via backend server for cooperative learning
- Demonstrate real-time telemetry and control

**Technical Challenge**: Transform simple toy trucks into intelligent racing vehicles capable of learning optimal racing lines through exploration and data analysis.

---

## 🏗️ System Architecture Overview

```
┌─────────────────────────────────────────────────────────────────┐
│                        TRUCK FIRMWARE (ESP32)                   │
│                                                                 │
│ ┌─────────────┐  ┌─────────────┐  ┌─────────────┐              │
│ │   Sensors   │  │  Control    │  │ Telemetry   │              │
│ │             │  │ State       │  │             │              │
│ │ • 4x US     │  │ Machine     │  │ • MQTT      │              │
│ │ • IMU       │  │             │  │ • JSON      │              │
│ │ • Compass   │  │ IDLE        │  │ • 1Hz       │              │
│ │             │  │ EXPLORE     │  │             │              │
│ │ Kalman      │  │ RECOVER     │  │             │              │
│ │ Filtering   │  │ STOP        │  │             │              │
│ └─────────────┘  └─────────────┘  └─────────────┘              │
│                                                                 │
└─────────────────────┼───────────────────────────────────────────┘
                      │ WiFi/MQTT
                      ▼
┌─────────────────────────────────────────────────────────────────┐
│                    BACKEND INFRASTRUCTURE                       │
│                                                                 │
│ ┌─────────────┐  ┌─────────────┐  ┌─────────────┐              │
│ │ MQTT Broker │  │ Database    │  │ Dashboard   │              │
│ │ (Pi5)       │  │ (SQLite)    │  │ (Flask)     │              │
│ │             │  │             │  │             │              │
│ │ • Message   │  │ • Telemetry │  │ • Real-time │              │
│ │   Routing   │  │ • Track     │  │   Monitoring│              │
│ │ • QoS       │  │   Data      │  │ • WebSocket │              │
│ └─────────────┘  └─────────────┘  └─────────────┘              │
│                                                                 │
│ ┌─────────────┐  ┌─────────────┐                               │ 
│ │ AI Training │  │ Race        │                               │
│ │ (Future)    │  │ Optimizer   │                               │
│ │             │  │ (Future)    │                               │
│ │ • Track     │  │             │                               │
│ │   Learning  │  │ • Line      │                               │
│ │ • Behavior  │  │   Optim.    │                               │
│ │   Analysis  │  │ • Speed     │                               │
│ └─────────────┘  └─────────────┘                               │
└─────────────────────────────────────────────────────────────────┘
```

---

## 🚧 Development Phases

### Phase 1: Track Exploration (Current Focus)
**Goal**: Autonomous track exploration with clean data collection

**Key Features**:
- Wall-following navigation for consistent lap completion
- Conservative speed prioritizing data quality over performance  
- Comprehensive sensor fusion for robust perception
- Real-time telemetry streaming for backend analysis

### Phase 2: Track Learning (Planned)
**Goal**: Extract track geometry and patterns from exploration data

**Key Features**:
- Data processing to identify track segments and characteristics
- Pattern recognition for turns, straightaways, and optimal racing lines
- Digital track map generation from telemetry history
- Performance baseline establishment

### Phase 3: Racing Optimization (Planned)
**Goal**: Intelligent racing with optimized strategies

**Key Features**:
- Racing line calculation for optimal cornering
- Continuous learning from racing performance data

---

## 🏆 ScaniaHack 2026 Context

### Innovation Highlights
- **Real Autonomous Vehicles**: Working hardware demonstration, not simulation
- **Scalable Architecture**: Foundation applicable to larger autonomous systems
- **Learning Capabilities**: Continuous improvement through data-driven optimization
- **Educational Value**: Open-source platform for autonomous systems learning

### Demonstration Capabilities
1. **Live Autonomous Racing**: Real-time racing demonstration with multiple vehicles
2. **Data Visualization**: Live telemetry dashboard showing decision-making process
3. **Learning Progress**: Demonstrable improvement in lap times and racing lines
4. **Cooperative Behavior**: Multi-vehicle coordination and strategy sharing

### Technical Challenges Addressed
- **Sensor Fusion**: Robust perception from multiple sensor modalities
- **Real-time Control**: Low-latency autonomous navigation and decision-making
- **Distributed Systems**: Networked vehicles sharing data and strategies
- **Online Learning**: Adaptation and improvement from real-world performance data

---

## 📊 Success Metrics

### Phase 1 (Exploration) - Current Target
- **Autonomous Laps**: Complete 10+ consecutive laps without intervention
- **Data Quality**: Consistent, reliable sensor data with minimal noise
- **System Reliability**: Robust operation with graceful error handling
- **Real-time Monitoring**: Live dashboard showing truck status and decision-making

### Phase 2 (Learning) - Development Target  
- **Track Mapping**: Accurate digital representation of track geometry
- **Pattern Recognition**: Automatic identification of racing line opportunities
- **Performance Analysis**: Baseline lap times and efficiency metrics

### Phase 3 (Racing) - Development Target
- **Optimized Racing**: Demonstrable improvement over exploration baseline
- **Multi-truck Racing**: Coordinated racing strategies between vehicles
- **Adaptive Behavior**: Real-time strategy adjustment based on conditions

---

## 🤝 Project Vision & Impact

### Educational Mission
This project serves as a comprehensive learning platform covering:
- **Embedded Systems**: Real-time control and sensor integration
- **Autonomous Navigation**: Perception, planning, and control algorithms  
- **Distributed Systems**: Multi-agent coordination and communication
- **Machine Learning**: Online learning and performance optimization

### Open Source Philosophy
- **Modular Design**: Accessible components for learning and modification
- **Comprehensive Documentation**: Detailed guides for all system aspects
- **Community Contribution**: Multiple entry points for different skill levels
- **Real-world Application**: Physical testing with immediate feedback

---

## 📚 Related Documentation

For detailed technical implementation, setup instructions, and development guides, see:

- **[Main Project README](readme.md)** - Complete project overview and quick start
- **[Firmware Documentation](EmbeddedSw/README.md)** - Detailed technical implementation
- **[Hardware Guide](toy-truck/electronics/hardware.md)** - Component specifications and assembly
- **[Dashboard Setup](truck_telemetry_dashboard/README.md)** - Real-time monitoring system
- **[OTA Process](arduino-ota-process.md)** - Wireless update procedures
- **[Development Setup](getstarted.md)** - Environment configuration and tools

---

**This project represents an innovative intersection of embedded systems, autonomous navigation, machine learning, and competitive programming - creating a comprehensive platform for hands-on learning and innovation in autonomous vehicle technology.**

*ScaniaHack 2026 - March 2026*

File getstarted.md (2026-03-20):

# How to get started

## Development environment

You will need Python3 and some kind of git-client.

The main software is Visual Studio Code, install it for your platform from https://code.visualstudio.com/

When vscode is up and running, select extensions and search for platformio. This is a complete toolkit for all kind of embedded development. We will use the arduino platform.

We are using C++ and installing some extensions for that is a good idea. 

We will probably use PHP, Python and other stuff as well, and vscode is really good for that too.

Now, when the development environment is installed, clone the github repo.

## How to start working with the repo

(More details for the git-magic in the wiki)

* Create a github-account if you don't already have one
* Navigate to https://github.com/teddycool/atmt
* Click the fork-button to get your own copy of this repo. Make sure to use the right branch.
* Now you have your own copy of the repo in your account and you can start working with it.
* Go the the local directory for your projects and start a terminal
* Run "git clone and the path to your fork to get all the files
* For your own coding you also need to create a new branch and work in that.
* When you are done with your changes, commit and push them to your github-account and create the new feature-branch there.
* Then use a pull-request from your github feature-branch back to the atmt main to show and discuss the changes you made with the rest of the team. 
* Don't forget to sync with the main-branch before you start working on a new feature.

## Open the project in VsCode

Now, start VsCode and open the folder named **EmbeddedSw** in vscode. This contains the PlatformIO project for the autonomous truck firmware.

1. Open Visual Studio Code
2. Navigate to File > Open Folder
3. Select the `EmbeddedSw` folder from your cloned repository
4. PlatformIO should automatically detect the project
5. Use the PlatformIO toolbar to build and upload to your ESP32

For different functionalities, check the `platformio.ini` file which defines multiple environments:
- `control_loop`: Main autonomous control system
- `minimal_test`: Basic ESP32 functionality testing
- `wifi_test`: WiFi connectivity testing

If you have an ESP32 dev-board ready, you should be able to build and upload successfully.

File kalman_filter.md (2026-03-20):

# Kalman filter 

(With help from Github Copilot and the Kalman filter Wikipedia page)

The Kalman filter is an algorithm that uses a series of measurements observed over time to estimate the state of a system. It is particularly useful for tracking the state of a system that is subject to noise and uncertainty. The Kalman filter is widely used in a variety of applications, including navigation, robotics, and signal processing.

The Kalman filter works by combining two sources of information: predictions from a mathematical model of the system and measurements from sensors. The filter uses these predictions and measurements to estimate the state of the system and to update its estimate as new measurements become available.

The Kalman filter is based on a set of mathematical equations that describe the evolution of the system over time. These equations include a process model that describes how the system's state changes over time and a measurement model that describes how the sensors provide measurements of the system's state.

The Kalman filter is an optimal estimator in the sense that it minimizes the mean squared error of the estimate. This means that the Kalman filter provides the best possible estimate of the system's state given the available measurements and the uncertainty in the system.

The Kalman filter is a recursive algorithm, meaning that it can update its estimate of the system's state as new measurements become available. This makes the Kalman filter well-suited for real-time applications where new measurements are continuously being received.

https://en.wikipedia.org/wiki/Kalman_filter for more information on the Kalman filter.

## Parameter values for the Kalman filter
To determine the values for the Kalman filter parameters (`processNoise`, `measurementNoise`, `estimationError`, and `initialValue`), you typically need to consider the specific application and the characteristics of the system you are modeling. Here are some general guidelines:

### 1 **Process Noise (`processNoise`)**: 

This parameter represents the uncertainty in the process model. If the system dynamics are well understood and predictable, this value can be small. If there is a lot of uncertainty or variability in the system, this value should be larger.

### 2. **Measurement Noise (`measurementNoise`)**: 
This parameter represents the uncertainty in the measurements. If the sensor providing the measurements is very accurate, this value can be small. If the sensor is noisy or unreliable, this value should be larger.

### 3. **Estimation Error (`estimationError`)**: 

This parameter represents the initial uncertainty in the estimate. If you have a good initial estimate, this value can be small. If the initial estimate is uncertain, this value should be larger.

### 4. **Initial Value (`initialValue`)**: 

This parameter represents the initial estimate of the state. This should be based on any prior knowledge you have about the system's state at the start.

## The GY-521 module 

which contains the MPU-6050 sensor, is commonly used for measuring acceleration and gyroscopic data. The measurement noise values for such sensors can vary, but typical values for the MPU-6050 are as follows:

### Accelerometer Noise: 
The noise level for the accelerometer is typically around 0.002 g/√Hz.

### Gyroscope Noise: 

The noise level for the gyroscope is typically around 0.03 °/s/√Hz.

These values can be used to estimate the measurement noise for your Kalman filter. However, the exact values may depend on your specific application and environment. Here is an example of how you might initialize the Kalman filter with these values:

```cpp
// Hypothetical values for the Kalman filter parameters for GY-521
float processNoise = 1.0f; // This value may need to be tuned based on your application
float measurementNoiseAccel = 0.002f; // Accelerometer noise
float measurementNoiseGyro = 0.03f; // Gyroscope noise
float estimationError = 1.0f; // Initial estimation error
float initialValue = 0.0f; // Initial value of the state
```

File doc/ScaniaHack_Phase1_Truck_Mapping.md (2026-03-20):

# Autonomous Truck Track Mapping — Phase 1
### ScaniaHack 2026 Project Notes

## Goal of Phase 1

The goal of Phase‑1 is **not fast driving** and **not AI yet**.

The goal is:

> Make the truck autonomously explore the track slowly and stream clean data so the backend can build a first track model.

Success criteria:

- Truck completes laps autonomously
- Data is streamed via MQTT
- Backend logs and visualizes runs
- Backend builds a first **track representation**

# System Architecture (Phase 1)

```
+-------------------------------------------------------------+
|                        TRUCK (ESP32)                        |
|                                                             |
|  Sensors                                                    |
|  -------                                                    |
|  UL  UR  UF  UB  (ultrasonic sensors)                       |
|  IMU (gyro/acc)                                             |
|  Compass                                                    |
|                                                             |
|        ↓                                                     |
|  Sensor Filtering                                           |
|        ↓                                                     |
|  Feature Extraction                                         |
|    width = UL + UR                                          |
|    center_error = UR - UL                                   |
|    front_blocked                                            |
|                                                             |
|        ↓                                                     |
|  Exploration Controller                                     |
|  (wall following + obstacle avoidance)                      |
|                                                             |
|        ↓                                                     |
|  Motor + Steering                                           |
|                                                             |
|        ↓                                                     |
|  MQTT Telemetry (10Hz)                                      |
|                                                             |
+---------------------- MQTT Broker --------------------------+
                               |
                               |
                               v
+-------------------------------------------------------------+
|                    BACKEND (Pi5 / Jetson)                   |
|                                                             |
|  MQTT Logger                                                |
|  - Store all messages                                       |
|                                                             |
|        ↓                                                     |
|  Run Database                                               |
|                                                             |
|        ↓                                                     |
|  Data Processor                                             |
|  - smooth signals                                           |
|  - detect turns / straights                                 |
|  - calculate track width                                    |
|                                                             |
|        ↓                                                     |
|  Lap Visualizer                                             |
|  - plots                                                    |
|  - debugging                                                |
|                                                             |
|        ↓                                                     |
|  Track Map Builder (later phases)                           |
|                                                             |
+-------------------------------------------------------------+
```

# Truck Software Strategy (C++)

The truck should **not try to build the map itself**.

Its job is:

- move safely
- collect reliable data
- repeat behavior consistently

## Core idea

A **simple exploration robot**.

Controller behavior:

1. Move slowly forward
2. Stay centered between track sides
3. Avoid collisions
4. Recover if stuck

# Truck Software Architecture

Recommended module structure:

```
main.cpp
sensors.cpp
filters.cpp
features.cpp
control.cpp
state_machine.cpp
telemetry.cpp
```

# Truck State Machine

```
IDLE
  |
  v
EXPLORE  --->  RECOVER
  |
  v
STOP
```

### IDLE
Truck waits for start command.

### EXPLORE
Normal exploration mode.

### RECOVER
Triggered when the truck gets stuck.

### STOP
Emergency stop.

# Derived Features on Truck

Raw sensors alone are not enough.

Compute useful values:

```
width = UL + UR
center_error = UR - UL
front_blocked = UF < threshold
rear_blocked = UB < threshold
```

These help both the controller and the backend.

# Exploration Controller Logic

Pseudo rules:

```
if front_distance < stop_threshold
    stop
    turn away from closest wall

else
    if center_error > deadband
        steer right
    else if center_error < -deadband
        steer left
    else
        go straight
```

Speed control:

```
normal_speed
slow_down_if_front_near
```

# Recovery Behavior

Trigger when:

```
front blocked for > 700 ms
```

Recovery steps:

1. Stop
2. Reverse briefly
3. Turn away from closest wall
4. Resume exploration

# Minimal C++ Exploration Controller Skeleton

```cpp
enum class Mode {
  IDLE,
  EXPLORE,
  RECOVER,
  STOP
};

enum class SteerCmd {
  LEFT,
  STRAIGHT,
  RIGHT
};

struct Sensors {
  float ul;
  float ur;
  float uf;
  float ub;
  float yaw;
  float heading;
};

struct Features {
  float width;
  float centerError;
  bool frontBlocked;
};

struct Command {
  int motorPwm;
  SteerCmd steer;
};

Mode mode = Mode::IDLE;

void deriveFeatures(const Sensors& s, Features& f) {
  f.width = s.ul + s.ur;
  f.centerError = s.ur - s.ul;
  f.frontBlocked = s.uf < 12.0;
}

Command computeExplore(const Sensors& s, const Features& f) {

  Command cmd;

  if (f.frontBlocked) {
    cmd.motorPwm = 0;

    if (s.ul < s.ur)
      cmd.steer = SteerCmd::RIGHT;
    else
      cmd.steer = SteerCmd::LEFT;

    return cmd;
  }

  cmd.motorPwm = 70;

  if (f.centerError > 3)
    cmd.steer = SteerCmd::RIGHT;
  else if (f.centerError < -3)
    cmd.steer = SteerCmd::LEFT;
  else
    cmd.steer = SteerCmd::STRAIGHT;

  return cmd;
}
```

# Telemetry Format (MQTT)

Recommended JSON payload:

```json
{
 "truck_id": "truck1",
 "seq": 1823,
 "t_ms": 123456789,
 "mode": "EXPLORE",

 "ul": 24.1,
 "ur": 31.7,
 "uf": 18.5,
 "ub": 40.0,

 "yaw_rate": -12.4,
 "heading": 97.2,

 "width": 55.8,
 "center_error": 7.6,

 "motor_pwm": 68,
 "steer_cmd": "LEFT"
}
```

Send at:

```
10 Hz
```

# Backend Strategy (Python)

Backend responsibilities:

1. Record runs
2. Replay data
3. Detect laps
4. Build first track model

Recommended tools:

```
paho-mqtt
pandas
sqlite / duckdb
matplotlib
```

# Backend Processing Pipeline

```
MQTT
 ↓
Logger
 ↓
Database
 ↓
Signal smoothing
 ↓
Feature extraction
 ↓
Lap detection
 ↓
Segment detection
 ↓
Track model
```

# First Track Model (Simple)

Do **not try to build a perfect map first**.

Start with a **topological map**.

Example:

```
straight
left turn
straight narrow
right turn
chicane
straight wide
```

Each segment stores:

```
average width
average yaw
duration
recommended speed
```

# Backend Track Model Example

```python
track_map = {
    "segments": [
        {"id":0, "type":"straight", "width":46.2, "speed":70},
        {"id":1, "type":"left_turn", "width":35.0, "speed":45},
        {"id":2, "type":"chicane", "width":33.1, "speed":40}
    ]
}
```

# Phase‑1 Milestone

### Truck

- exploration controller works
- recovery works
- stable telemetry
- one autonomous lap possible

### Backend

- logs runs
- detects laps
- segments turns
- produces first map

# Next Phase (Phase 2)

Once Phase‑1 works:

- align multiple laps
- average track segments
- compute optimal speed
- send map back to truck
- start learning lap optimization

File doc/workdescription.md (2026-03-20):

# A Toy Autonomous Monster Truck, work description

This is the working description for the hardware. When this is done we have a nice platform to use for the software development.

## Starting material
I started with a cheap radio-controlled 'monster-truck' -toy in scale 1:24. I bought mine at Biltema for about 200 SEK (20€). I actually bought two of them because these models probably changes pretty fast and it´s good idea to have a spare, for several reasons...
https://www.biltema.se/fritid/leksaker/radiostyrda-leksaker/rc-turbo-dragon-truck-124-24-ghz-2000040669

Starters

Before starting to rip it apart its also a good idea to try it out as it is, to see that the motor and steering works as expected.

## Rip it apart!
Now the fun starts!

Remove the body from the chassis. In my case there where two screws and some 'snap-ins'.

Before taking the electronics apart I measured the signals for the motor and steering. In my case these where really simple. Battery-power and reversed for backwards.

Next step was to get into the electronics. I quickly decided to keep the battery compartment and the on/off switch and then design my own PCB with the same form-factor as the original.

Next step was to de-solder the cables for the motor and steering and also the battery connection from the original PCB.

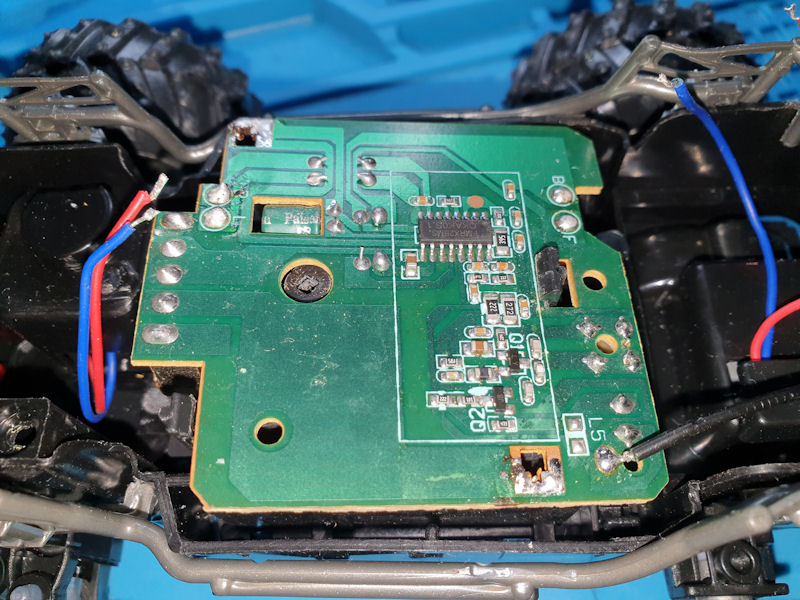
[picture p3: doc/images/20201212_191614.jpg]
PCB


When I had removed the PCB I enforced the battery connections from the battery compartment with some glue.

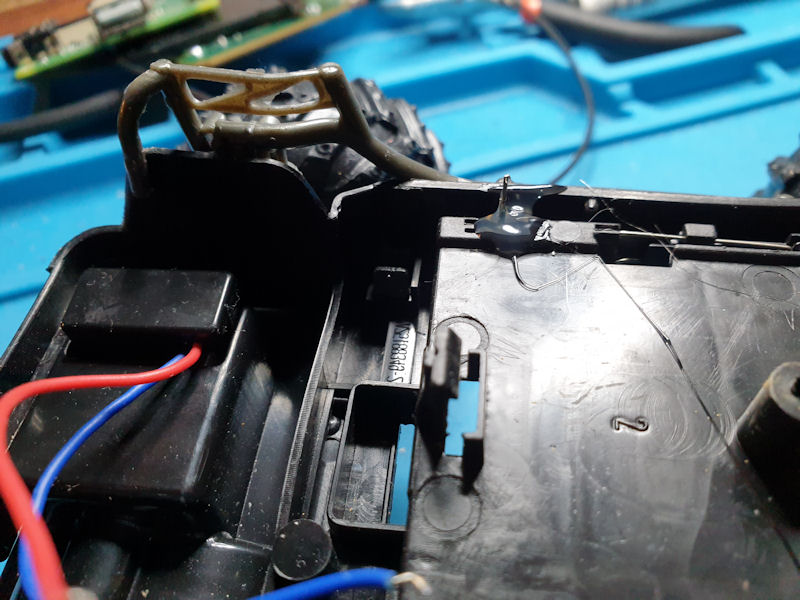
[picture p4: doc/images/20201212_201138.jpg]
Battery connector


When the original PCB was removed I made a sketch and took measurements for the form-factor. Since the PCB was mounted with 'snap-ins' it was important to get these measurements correct. The connections to the battery-compartment and the on/off switch also needs to be correct.

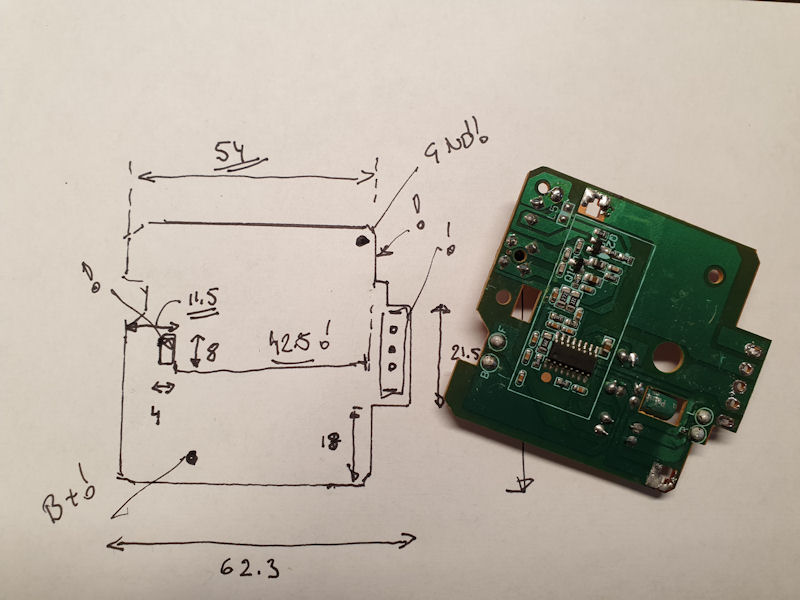
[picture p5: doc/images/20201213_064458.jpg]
Measure PCB


Ok, now it's time to cut out the not used part of the body and chassis to make room for the new electronics. A Dremel comes into use but be careful not to cut too much.

Now the body and chassis are prepared! The connectors on the picture are MTA-100 2 pole and these are good for using as a side connector to a PCB together with 90 degree header-pins.

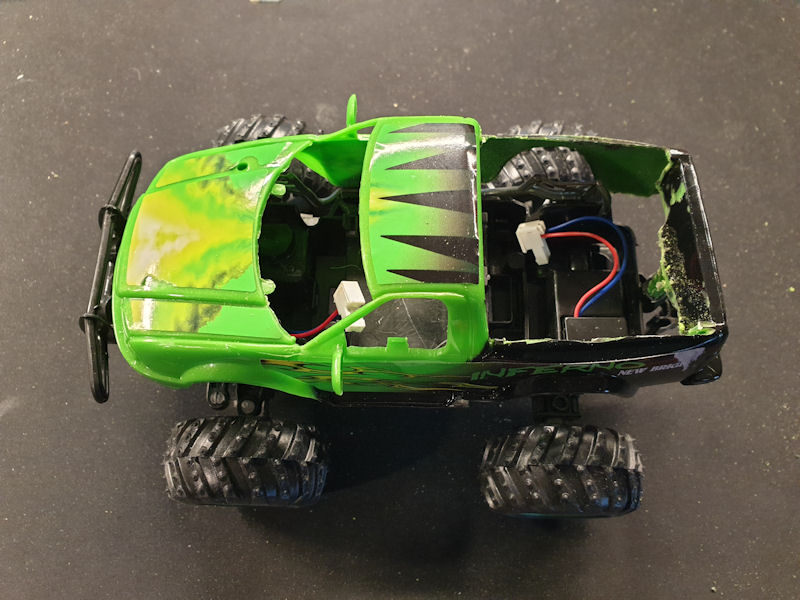
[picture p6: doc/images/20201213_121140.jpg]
Ripped apart


## Circuit design
This is a long process... First I had some ideas what to do and then I tried to test it as much as possible, before starting with the schematics.

### Power supply
I decided to use the 3 AA batteries from the original design for simplicity, at least in the first version. I  need a 3.3 low dropout voltage regulator and decided on a LP2989, cheap simple and in an SMD package and it can handle the 500mA that the ESP32 needs. The power to the motors will be taken directly from the batteries. Also the power-switch will be reused.

### Motor control
I will use a SMD L293D circuit for this. This has support for 2 motors with is exactly what I need.

### Distance sensors
I'll use 4 * HC-SR04. These are 5V sensors but work with 4.5 directly from the battery and also with the logic levels of the ESP32.

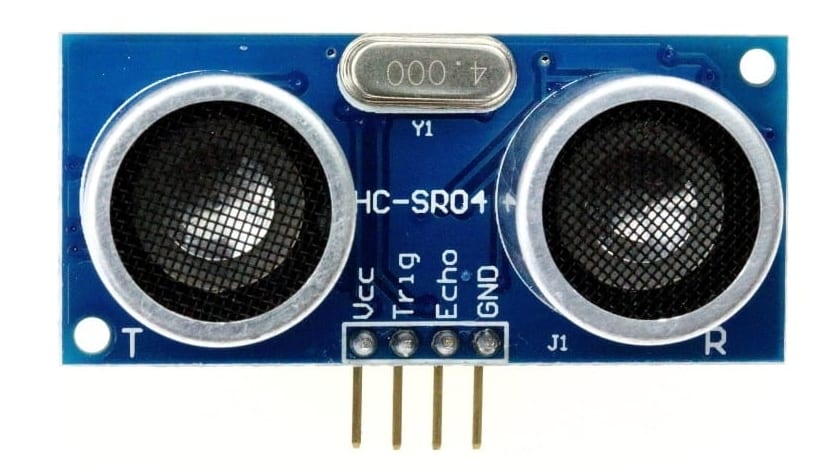
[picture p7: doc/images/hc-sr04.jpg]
Distance sensor


### Other sensors
I'll include a pair of I2C connectors to use with accelerometer and electronic compass or some other I2C sensor.

### Light
There would be cool with some lights and I'll include a couple of IO connections for that.

### Schematics
The circutry is shown in mt-schema-v1.pdf

### PCB
As mentioned above I used the same form-factor and measurements as the original PCB to have a good fit in the chassis. The first version of the PCB is two-sided has the MCU on the top side and the power-supply and the motor-control on the back-side. I am using SMD parts as much as possible to reduce the size. The version 1 of the PCB (shown on the pictures below)had some issues and there is now a version 2 in the toy-truck/electronics folder.

The PCB is a shared design at aisler.net: https://aisler.net/p/JDIHIDIT

There are connectors for the motors, the distance-sensors, 2x I2C, programming interface, boot-mode and JTAG

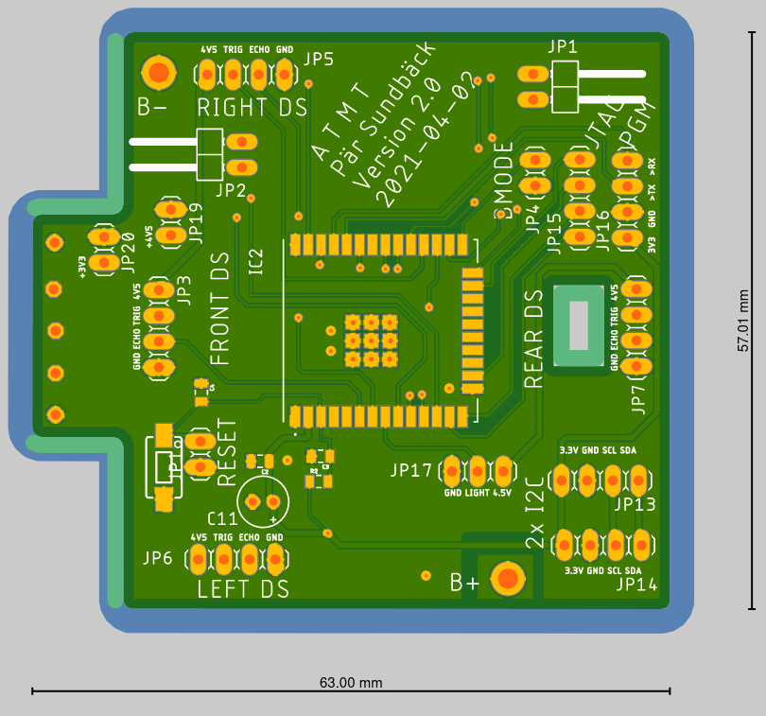
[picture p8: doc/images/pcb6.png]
PCB top

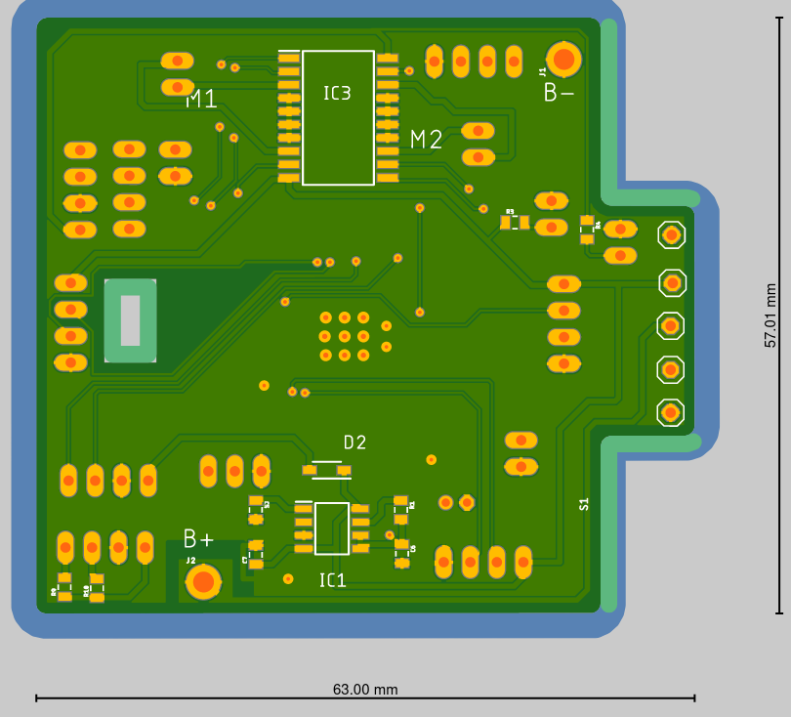
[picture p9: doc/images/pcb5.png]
PCB bottom


## Car body
Again, Biltema is a good supplier. I wanted my monster truck to be painted in black and with some yellow and red 'flames'.

To do this I needed a good primer, some paint and a coating. All as spray paint.  All this spray-paint was bought at Biltema, around 70 SEK or 7€ per 'bottle'.

Pictures shows the primer and the first layer of black paint. I can see that some polishing is needed before the next layer of paint.

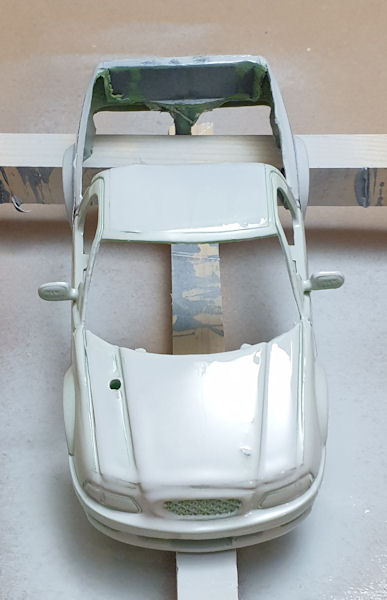
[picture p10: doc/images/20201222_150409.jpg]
primer
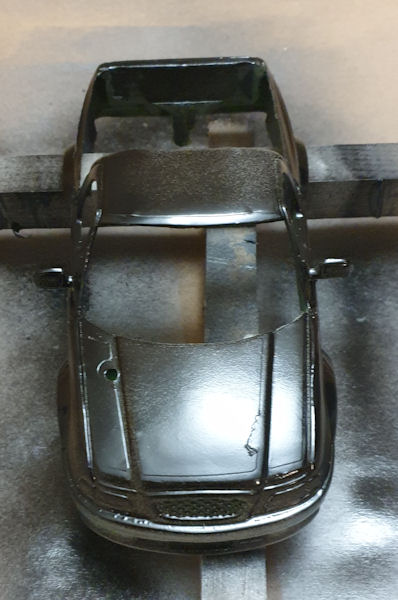
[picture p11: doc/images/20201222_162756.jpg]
first layer
 

## Software
Software for the actual control system is described else-where in this project..

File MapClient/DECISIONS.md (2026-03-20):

# Decisions

| # | Date | User | Decision | Rationale |
|---|---|---|---|---|
| 1 | 2026-03-19 | ajuan | Use modular `ExploreStrategy` pattern in truck_simulator.py | Allows swapping exploration logic without changing truck core; enables testing embedded algorithm in simulation |
| 2 | 2026-03-19 | ajuan | `EmbeddedExplore` keeps all state inside strategy, not on `Truck` | Strategy-specific state (turn counters, filters, recovery timer) should not pollute the truck model |
| 3 | 2026-03-19 | ajuan | Boundary inference uses percentile trimming not min/max | Robust to sensor noise outliers that would otherwise inflate the estimated boundary |
| 4 | 2026-03-19 | ajuan | Removed MCP references from AGENTS.md | MCP server not available in this project setup; local `.context/` is the sole authority |

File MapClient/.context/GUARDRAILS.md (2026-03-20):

# Guardrails

These rules always apply. If any instruction conflicts with these, stop and ask the user.

## Mandatory Preflight Gate
Before starting any non-trivial task the agent MUST:
1. Read `AGENTS.md` to confirm active truck model and workflow rules.
2. Read `.context/TASK.md` to confirm the active task.
3. Read `.context/STATE.md` to recover current context.
4. Read `.context/PLAN.md` to know where to continue.
5. Write a plan to `.context/PLAN.md` before doing any implementation work.

## MQTT payload structure
If you feel that you need to change the mqtt payload structure stop. It has to follow this rigid json structure
{
  "truck_id": string,
  "seq": int,
  "t_ms": int,
  "mode": string,
  "ul": float,
  "ur": float,
  "uf": float,
  "ub": float,
  "yaw_rate": float,
  "heading": float,
  "compass": float,
  "mag_x": float,
  "mag_y": float,
  "mag_z": float,
  "acc_x": float,
  "acc_y": float,
  "acc_z": float,
  "width": float,
  "center_error": float,
  "front_blocked": bool,
  "cmd_pwm": int,
  "cmd_steer": srting
}

## Safety Rules
- Never delete files without explicit user confirmation.
- Never push to remote git without explicit user instruction.
- Never modify hardware configuration values (broker IP, PWM limits, sensor thresholds) without explicit user instruction.
- Never commit credentials, IP addresses, or hardware-specific secrets to version control without user approval.

## Code Rules
- Prefer the minimum design that satisfies the current need.
- Do not add features, generalisations, or flexibility beyond what is asked. Propose extras as explicit user decisions.
- Comments must explain *why*, not restate what the code does line by line.
- Whenever a shared variable is added, removed, renamed, or has its unit changed, update `docs/VARIABLE_MODEL.md` in the same work item.

## Context Hygiene
- `STATE.md` is live working memory for the current task only — keep it short.
- `PLAN.md` is the execution plan — update it at every meaningful step.
- `PROJECT_HISTORY.md` is append-only — do not edit past entries.
- `TASK.md` is the task definition — do not update it during execution unless the task itself changes.
- Log every file addition or deletion in `PROJECT_HISTORY.md`.

## Conflict Handling
- If instructions conflict, append the conflict to `CONFLICTS.md` in table format, stop, and wait for user resolution.

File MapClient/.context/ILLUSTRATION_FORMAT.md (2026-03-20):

# Illustration Format

## Default Style
- Clean, minimal line art or block diagrams.
- Neutral background (white or very light grey).
- Label only what is essential for understanding — avoid dense text on images.
- Use arrows to show data/control flow direction.
- Colour sparingly: one accent colour per logical group.

## Architecture Diagrams
- Show components as labelled boxes.
- Show MQTT topics as labelled arrows between publisher and subscriber.
- Include field boundary and sensor rays when illustrating truck navigation.

## Notes
- Current image models render dense text poorly — keep on-image labels short.
- Prefer SVG-style descriptions when generating prompts for vector tools.

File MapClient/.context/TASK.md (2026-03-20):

# Task

## Active Task
Port the ESP32 control loop from `EmbeddedSw/src/z_main_control_loop.cpp` to a clean
Python file (`MapClient/embedded_control.py`).

## Scope / Constraints
- Faithful translation of the C++ logic — same state machine, same config defaults, same algorithm order.
- Simple and readable; no extra features beyond what the C++ does.
- Must be compatible with `truck_simulator.py`'s `ExploreStrategy` interface (`step(truck, sensors)`).
- No modification to `truck_simulator.py` unless the user asks.

## Definition of Done
- `embedded_control.py` exists in `MapClient/`.
- Contains `EmbeddedController` with the same IDLE→EXPLORE→RECOVER state machine.
- Config defaults match the C++ `ControlConfig` struct exactly.

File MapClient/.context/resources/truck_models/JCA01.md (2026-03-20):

# Truck Model: JCA01

## Overview
Small modular toy truck with ESP32 control board. Scale approximately 20:1.

## Drivetrain
- Dual independent rear wheel motors (left and right driven separately).
- Front steering via servo.

## Sensors
| Sensor | Count | Notes |
|---|---|---|
| Ultrasonic (HC-SR04 or equivalent) | 4 | Front, back, left, right. Max range ~199 cm. |
| MPU-6050 | 1 | 6-axis IMU: accelerometer + gyroscope. |
| Compass (HMC5883 or equivalent) | 1 | Heading in degrees. |

## Expansion
- I2C expansion board for additional IO (lights, etc.).
- I2C switch for additional I2C devices (LV0x / LV5x TOF laser sensors).

## Control Board
- ESP32 (dual-core, Wi-Fi + Bluetooth).
- Firmware: PlatformIO project in `EmbeddedSw/`.

## Communication
- MQTT over Wi-Fi.
- Telemetry topic: `{TRUCK_ID}/telemetry` at 1 Hz (configurable).

## Known Characteristics
- Sensor polling at 50 Hz (20 ms loop).
- EMA filter alpha: 0.35 (ultrasonics), 0.25 (IMU).
- Front stop threshold: 12 cm. Slow threshold: 20 cm.
- Side collision threshold: 6 cm.
- Recovery: reverse 500 ms, turn 600 ms.

## Notes
- Values above are verified from `EmbeddedSw/src/z_main_control_loop.cpp`.
- Update this file if hardware or firmware parameters change.

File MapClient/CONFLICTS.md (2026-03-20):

# Conflicts

| # | Date | File(s) | Conflict Description | Resolution | Resolved By |
|---|---|---|---|---|---|
| — | — | — | No conflicts recorded | — | — |

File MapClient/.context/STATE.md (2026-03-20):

# State

## Active Task
Port z_main_control_loop.cpp → embedded_control.py — COMPLETE.

## Live Facts
- Active truck model: JCA01
- `embedded_control.py` created in MapClient/.
- `EmbeddedController` is a faithful port of the C++ control loop (same config defaults, same algorithm order).
- Compatible with truck_simulator.py ExploreStrategy interface: `step(truck, sensors)`.
- MQTT broker: 192.168.2.2:1883

## Blockers
None.

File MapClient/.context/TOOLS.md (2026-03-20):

# Tools

## Available
| Tool | Notes |
|---|---|
| Python 3.13 | Runtime for all MapClient scripts |
| paho-mqtt | MQTT client — `pip install paho-mqtt` |
| matplotlib | Visualization — `pip install matplotlib` |
| numpy | Numerics — `pip install numpy` |
| python3-tk | TkAgg backend for matplotlib — `sudo apt install python3-tk` |
| mosquitto_pub / mosquitto_sub | CLI MQTT tools for broker testing |

## Runtime Environment
- Virtual environment at `MapClient/venv/`
- Activate: `source venv/bin/activate`

## Not Available
- MCP server / shared-resources — not configured for this project.
- ROS / any robotics middleware.

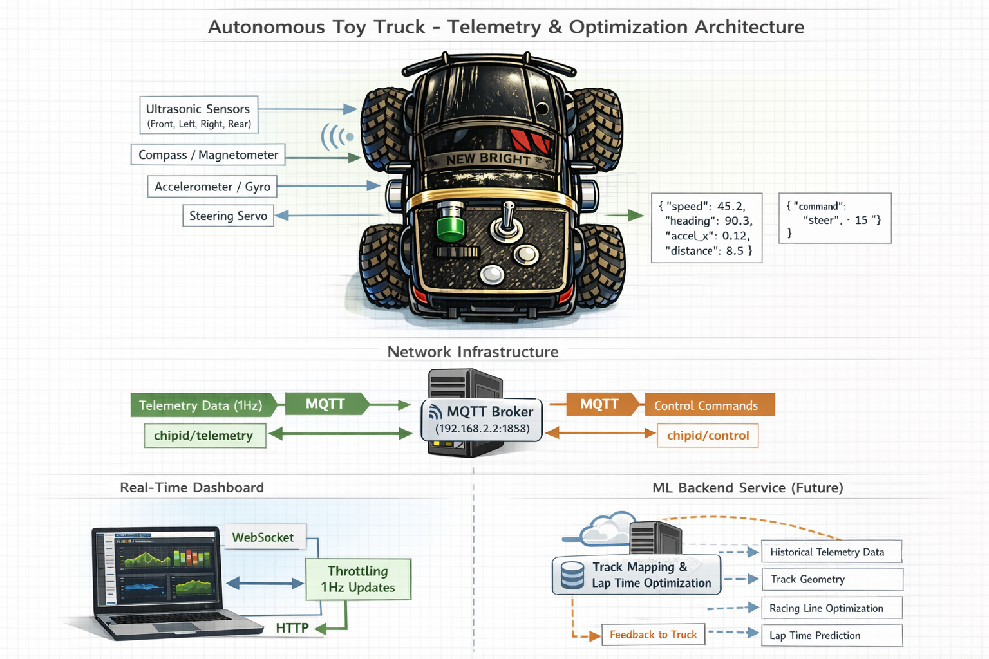
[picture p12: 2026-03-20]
posters/telemetry-architecture-a3.png

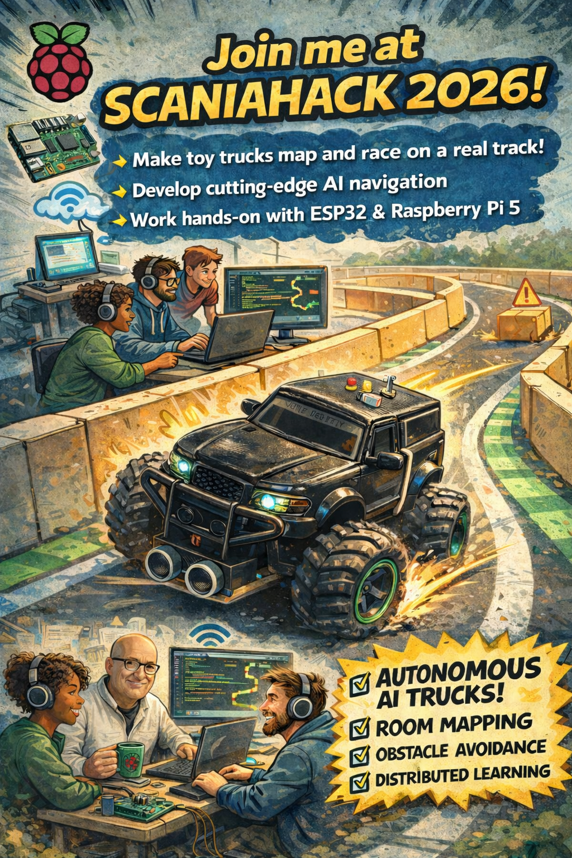
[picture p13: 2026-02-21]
posters/poster.png

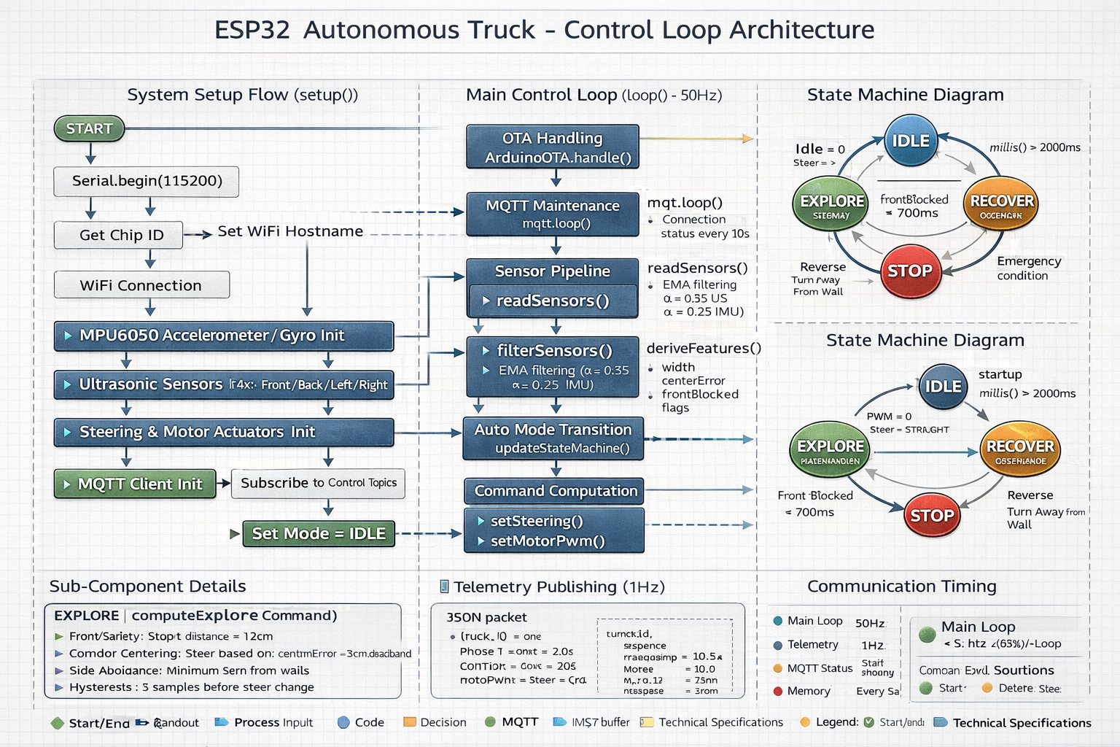
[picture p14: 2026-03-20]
posters/control-loop.png

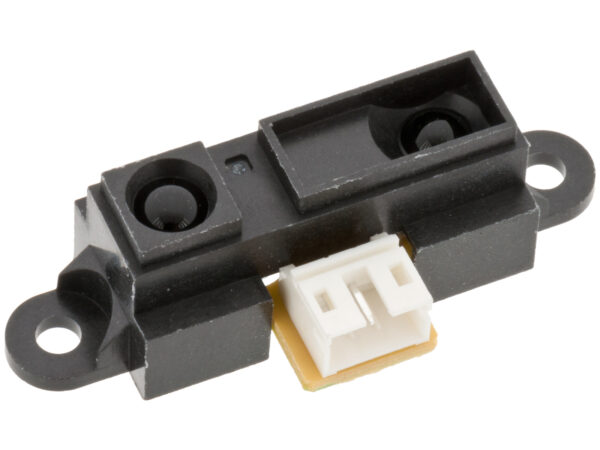
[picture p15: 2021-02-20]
doc/images/41004830-1-600x450.jpg

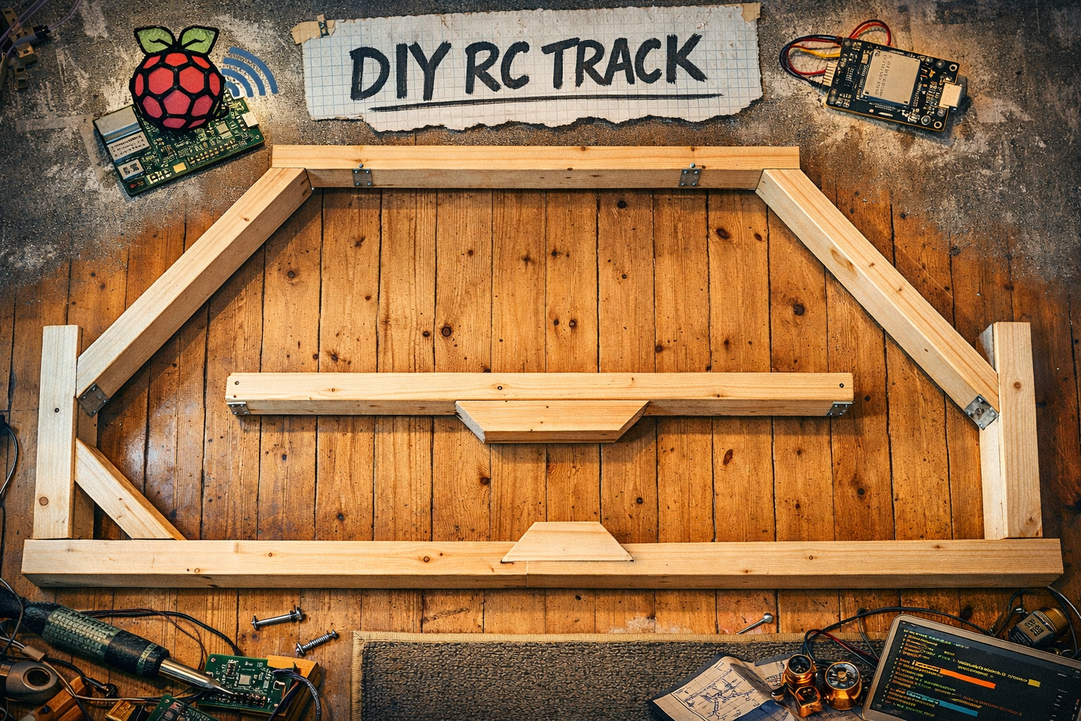
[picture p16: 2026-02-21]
doc/images/rc-track-ai-1.png

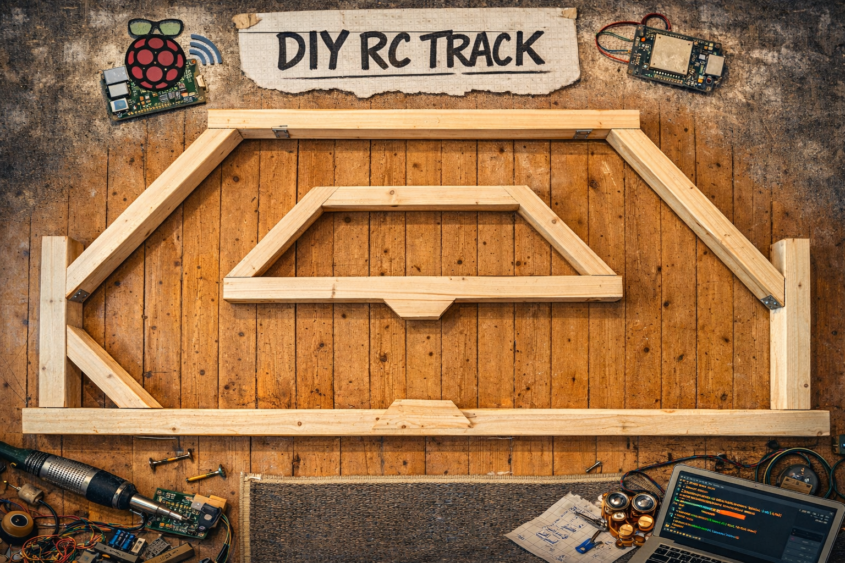
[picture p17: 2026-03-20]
doc/images/rc-track-2.png

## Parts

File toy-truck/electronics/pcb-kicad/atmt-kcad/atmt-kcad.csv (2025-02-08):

Id | Designator | Footprint | Quantity | Designation | Supplier and ref
1 | D2 | LED_D3.0mm | 1 | PowerOn
2 | J2 | PinHeader_1x02_P2.54mm_Vertical | 1 | PowerSw
3 | J14 | PhoenixContact_MSTBA_2,5_2-G-5,08_1x02_P5.08mm_Horizontal | 1 | Motor
4 | J11 | SolderWire-1.5sqmm_1x01_D1.7mm_OD3mm | 1 | BAT+
5 | U1 | ESP32-WROOM-32U | 1 | ESP32-WROOM-32U
6 | C6 | CP_Radial_D5.0mm_P2.00mm | 1 | 22u
7 | J8 | PinHeader_1x04_P2.54mm_Vertical | 1 | PRG
8 | J13 | PhoenixContact_MSTBA_2,5_2-G-5,08_1x02_P5.08mm_Horizontal | 1 | Steering
9 | J6 | PinHeader_1x04_P2.54mm_Vertical | 1 | US-Left
10 | J7 | PinHeader_1x04_P2.54mm_Vertical | 1 | I2Cx2
11 | J17 | PinHeader_1x03_P2.54mm_Vertical | 1 | Buck/Boost
12 | J4 | PinHeader_1x04_P2.54mm_Vertical | 1 | US-Rear
13 | J1 | PinHeader_1x02_P2.54mm_Vertical | 1 | Reset
14 | J5 | PinHeader_1x04_P2.54mm_Vertical | 1 | US-Right
15 | J10 | PinHeader_1x04_P2.54mm_Vertical | 1 | JTAG
16 | J9 | PinHeader_1x04_P2.54mm_Vertical | 1 | I2C_1
17 | J16 | PinHeader_1x03_P2.54mm_Vertical | 1 | Light
18 | J12 | SolderWire-1.5sqmm_1x01_D1.7mm_OD3mm | 1 | BAT-
19 | J3 | PinHeader_1x04_P2.54mm_Vertical | 1 | US-Front
20 | J15 | PinHeader_1x02_P2.54mm_Vertical | 1 | BOOT
21 | R6,R5,R2 | R_0805_2012Metric_Pad1.20x1.40mm_HandSolder | 3 | 10k
22 | C1,C4 | C_0805_2012Metric_Pad1.18x1.45mm_HandSolder | 2 | 10u
23 | C7,C2,C3 | C_0805_2012Metric_Pad1.18x1.45mm_HandSolder | 3 | 100n
24 | R3 | R_0805_2012Metric_Pad1.20x1.40mm_HandSolder | 1 | 470k
25 | U4 | SO-20_STM | 1 | L293DD
26 | D1 | D_SMC | 1 | B340
27 | R4 | R_0805_2012Metric_Pad1.20x1.40mm_HandSolder | 1 | 100k
28 | U3 | SOIC-16_3.9x9.9mm_P1.27mm | 1 | 4504
29 | R7 | R_0805_2012Metric_Pad1.20x1.40mm_HandSolder | 1 | 470
30 | C5 | C_0805_2012Metric_Pad1.18x1.45mm_HandSolder | 1 | 1u
31 | R1 | R_0805_2012Metric_Pad1.20x1.40mm_HandSolder | 1 | 330k
32 | U2 | SOIC-8_3.9x4.9mm_P1.27mm | 1 | LP2987-3.3

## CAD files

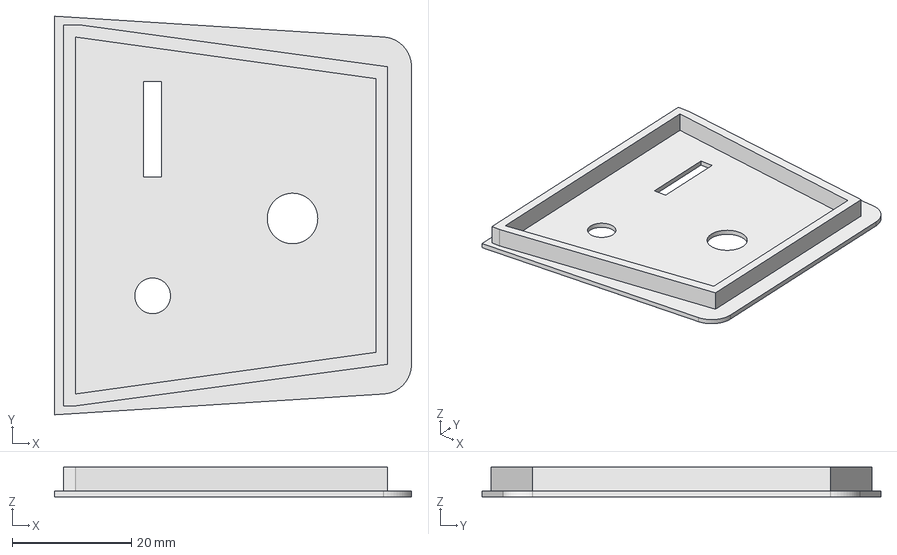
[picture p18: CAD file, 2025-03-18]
toy-truck/Chassi-prep/body-top.FCStd
60.0 x 67.0 x 5.00 mm

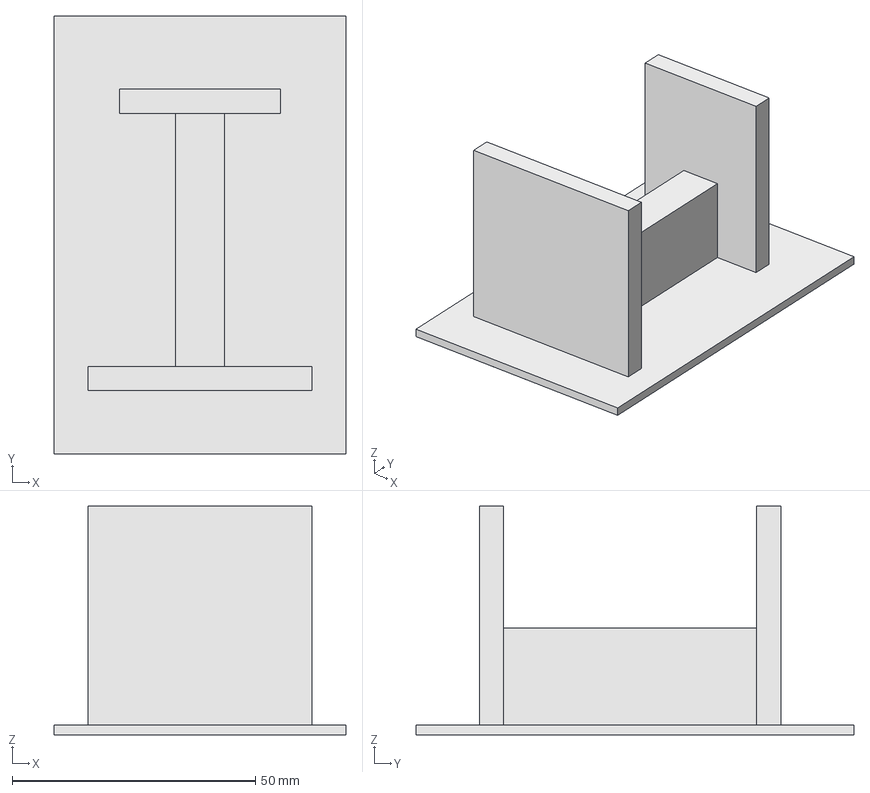
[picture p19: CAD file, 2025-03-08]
toy-truck/table-stand.FCStd
60.0 x 90.0 x 47.0 mm

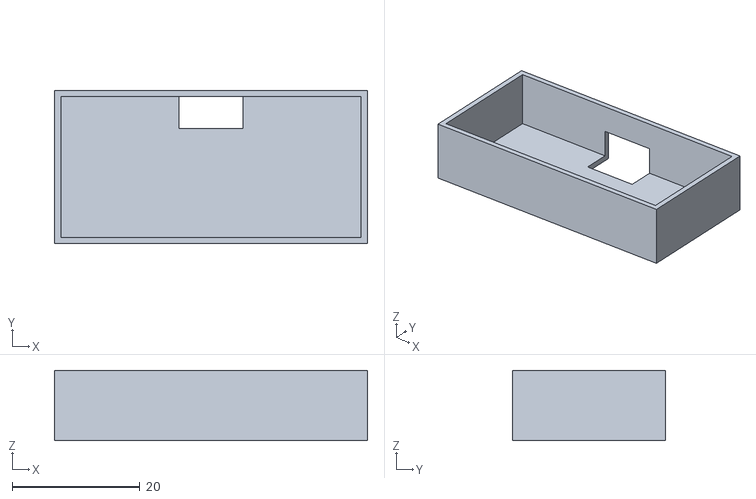
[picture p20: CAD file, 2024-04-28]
toy-truck/Chassi-prep/sr04-rear-3.stl
49.0 x 24.0 x 11.0

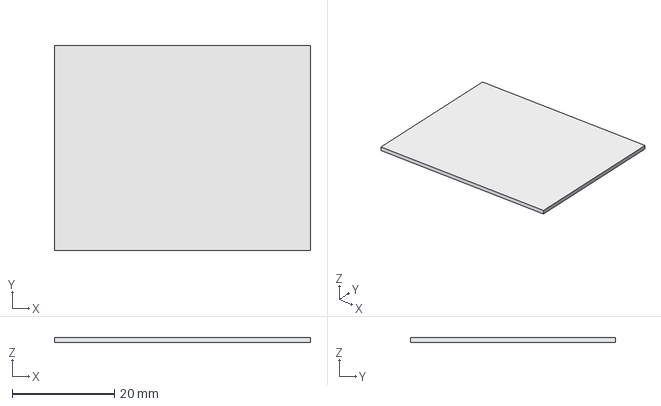
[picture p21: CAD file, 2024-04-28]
toy-truck/Chassi-prep/sidebracket.FCStd
50.0 x 40.0 x 1.00 mm

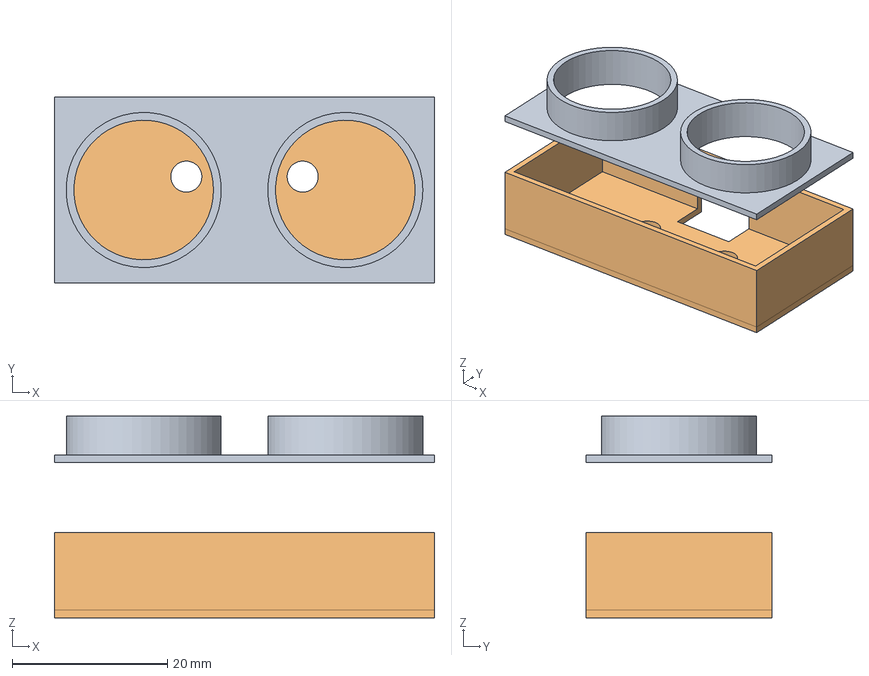
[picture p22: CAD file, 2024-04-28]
toy-truck/Chassi-prep/d-sensor-bracket.FCStd
49.0 x 24.0 x 26.0 mm
Front
Rear

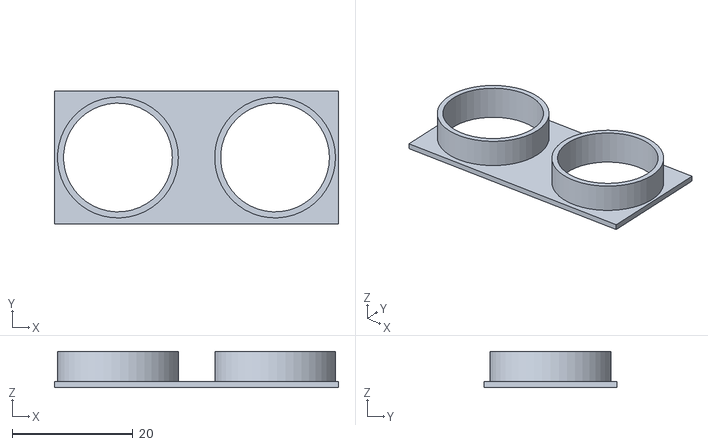
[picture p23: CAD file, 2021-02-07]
toy-truck/Chassi-prep/sr04-1.stl
47.0 x 22.0 x 6.00

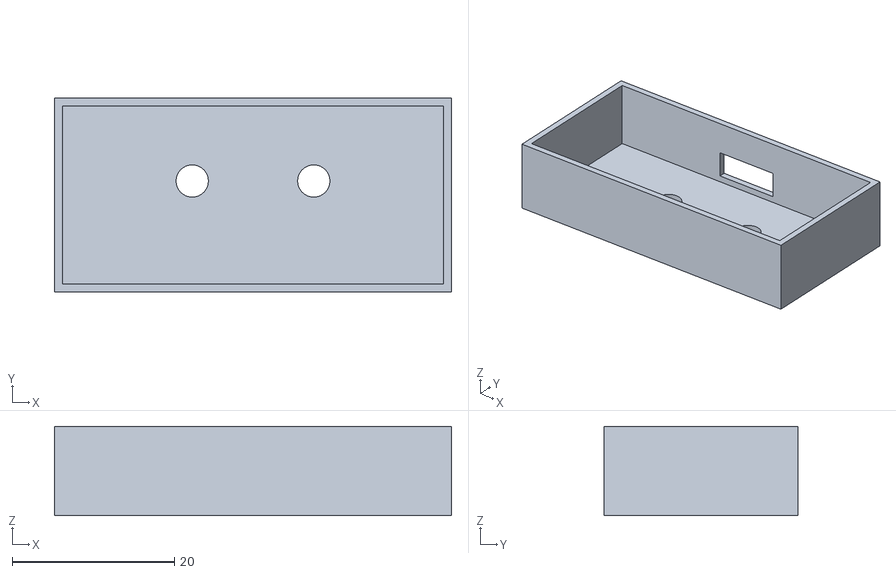
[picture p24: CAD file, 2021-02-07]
toy-truck/Chassi-prep/sr04-rear-2.stl
49.0 x 24.0 x 11.0

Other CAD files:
toy-truck/Chassi-prep/body-top-25-1.stl
toy-truck/table-stand.stl

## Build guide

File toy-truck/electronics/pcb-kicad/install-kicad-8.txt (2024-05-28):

sudo add-apt-repository ppa:kicad/kicad-8.0-releases
sudo apt update
sudo apt install kicad

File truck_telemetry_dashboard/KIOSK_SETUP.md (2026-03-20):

# Truck Telemetry Dashboard - Kiosk Mode Setup

This directory contains scripts to set up your Flask dashboard to run in kiosk mode on a Raspberry Pi 3B+ with Bookworm Lite.

## Quick Setup

1. **Copy this entire folder to your Raspberry Pi** (e.g., to `/home/pi/truck_telemetry_dashboard/`)

2. **Run the installation script:**
   ```bash
   chmod +x install_kiosk.sh
   sudo ./install_kiosk.sh
   ```

3. **Reboot when prompted:**
   ```bash
   sudo reboot
   ```

The system will automatically start in kiosk mode showing your dashboard!

## What the Installation Does

### Installs Minimal GUI Environment:
- **Xorg** - X11 window system
- **Openbox** - Lightweight window manager
- **LightDM** - Display manager for auto-login
- **Chromium** - Browser for kiosk mode
- **Unclutter** - Hides mouse cursor

### Creates System Service:
- **truck-dashboard.service** - Auto-starts your Flask app
- Runs as the `pi` user
- Auto-restarts on failure
- Starts after network is available

### Configures Kiosk Mode:
- Auto-login to desktop
- Automatically opens Chromium in fullscreen
- Disables screen saver and power management
- Hides mouse cursor
- Points browser to `http://localhost:5001`

## Manual Service Management

If you only want the service without the GUI (headless mode):

```bash
chmod +x service_manager.sh

# Install service only
./service_manager.sh install

# Control the service
./service_manager.sh start
./service_manager.sh stop
./service_manager.sh restart
./service_manager.sh status
./service_manager.sh logs
```

## Helper Scripts

After installation, these scripts are available:

- **`./status.sh`** - Check service and GUI status
- **`./start_kiosk.sh`** - Manually start kiosk mode
- **`./stop_kiosk.sh`** - Stop kiosk mode and return to terminal
- **`./service_manager.sh`** - Manage just the service

## Remote Access

Your dashboard will be accessible from other devices on the network:
```
http://[PI_IP_ADDRESS]:5001
```

## Troubleshooting

### Check Service Status:
```bash
sudo systemctl status truck-dashboard
```

### View Logs:
```bash
sudo journalctl -u truck-dashboard -f
```

### Check if GUI is Running:
```bash
sudo systemctl status lightdm
```

### Return to Headless Mode:
```bash
sudo systemctl set-default multi-user.target
sudo systemctl disable lightdm
sudo reboot
```

### Return to Kiosk Mode:
```bash
sudo systemctl set-default graphical.target
sudo systemctl enable lightdm
sudo reboot
```

## Configuration Notes

### Network Configuration
Make sure your MQTT broker IP address is correct in `app.py`:
```python
MQTT_BROKER = "192.168.2.2"  # Update this to match your network
```

### Display Settings
If you need to adjust the display resolution or orientation, you can modify `/boot/config.txt`:
```
# For specific resolution
hdmi_force_hotplug=1
hdmi_group=2
hdmi_mode=82  # 1920x1080 60Hz

# For screen rotation
display_rotate=1  # 90 degrees
```

### Browser Settings
To modify the browser behavior, edit the autostart script that gets created during installation.

## System Requirements

- Raspberry Pi 3B+ or newer
- Raspberry Pi OS Bookworm Lite (headless)
- At least 2GB SD card space for GUI components
- Network connection for MQTT communication

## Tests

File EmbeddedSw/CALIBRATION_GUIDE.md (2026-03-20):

# ATMT Racing Truck - Calibration and Setup Guide

## 🎯 Three-Stage Compass Solution

### **Stage 1: Initial Calibration Program**
Use for first-time setup and whenever you need to recalibrate:

```bash
# Upload calibration program
pio run -e calibration -t upload -t monitor

# Follow prompts to:
# 1. Calibrate compass (manually rotate truck)
# 2. Test all sensors  
# 3. Test actuators
# 4. Configure settings
# 5. Save everything to EEPROM
```

### **Stage 2: Racing Program**  
The main autonomous racing firmware:

```bash
# Upload racing program
pio run -e control_loop -t upload -t monitor

# Racing program will:
# 1. Load calibration from EEPROM (from Stage 1)
# 2. Start racing immediately with accurate compass  
# 3. Continue improving calibration during racing (background)
```

### **Stage 3: Background Auto-Calibration**
Automatic fallback if EEPROM data is corrupted or missing:

- Racing program detects missing calibration
- Enables background auto-calibration during driving
- Compass accuracy improves as truck turns during races
- Self-calibrates without any manual intervention

## 🔧 Usage Workflow

### **Initial Setup (one time):**
1. Upload calibration program: `pio run -e calibration -t upload`
2. Follow calibration menu to calibrate compass and test hardware
3. Calibration gets saved to EEPROM permanently

### **Racing (normal operation):**
1. Upload racing program: `pio run -e control_loop -t upload`  
2. Truck starts immediately with perfect compass accuracy
3. Background refinement continues during racing

### **Emergency/Corruption Recovery:**
- If EEPROM gets corrupted, racing program automatically falls back to background auto-calibration
- No manual intervention needed - just drive and compass improves automatically

## ✅ **Perfect for Racing!**
- **Setup once**: Use calibration program for initial setup
- **Race anytime**: Load racing program and go immediately  
- **Zero maintenance**: Background calibration handles everything automatically
- **Bulletproof**: Automatic fallback if anything goes wrong

## 📁 **Files**
- `z_calibration_setup.cpp` - Dedicated calibration program
- `z_main_control_loop.cpp` - Main racing program  
- `platformio.ini` - Build environments for both programs

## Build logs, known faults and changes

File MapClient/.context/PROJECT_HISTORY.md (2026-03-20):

# Project History

## 2026-03-19 — Created embedded_control.py (ajuan)
- Faithful Python port of `EmbeddedSw/src/z_main_control_loop.cpp`.
- `EmbeddedController` class: IDLE→EXPLORE→RECOVER state machine, EMA sensor filtering,
  corridor centering, side avoidance, steering hysteresis, timed recovery sequence.
- Config defaults match C++ `ControlConfig` exactly (frontStopDist=12, recoverReverseMs=1000, etc.).
- Compatible with `truck_simulator.py` ExploreStrategy interface.

## 2026-03-19 — Added real-time path visualization to truck_simulator.py (ajuan)
- Added `SimVisualizer` class to `truck_simulator.py`: matplotlib window with red room boundary, red obstacle rectangles, dashed steelblue path line, current-position dot. FuncAnimation at 150 ms; thread-safe with a lock.
- Added `--visualize` CLI flag; matplotlib import guarded like paho-mqtt.
- Refactored `run()`: when `--visualize`, simulation runs in a daemon thread and matplotlib owns the main thread. Without the flag, behaviour is identical to before.
- No new files added.

## 2026-03-19 — Added SLAM to map_visualization.py (ajuan)
- Implemented `OccupancyGrid`: 400×400 cells at 2 cm/cell, log-odds updates, Bresenham ray tracing.
- Implemented `SLAMProcessor`: pose from payload x/y/heading (simulator) or dead-reckoned; one truck at a time.
- `MQTTListener` routes first discovered truck to SLAM.
- Figure restructured to 3-column GridSpec: 2×2 sensor charts left, SLAM map right.
- SLAM panel: live occupancy grid image (gray_r), dashed trajectory, position dot, heading arrow, auto-zoom.

## 2026-03-19 — Replaced map_visualization.py with sensor distance visualizer (ajuan)
- Removed all previous path/boundary visualization code.
- New implementation: 2×2 rolling time-series subplots, one per sensor (uf, ub, ul, ur).
- One coloured line per truck per subplot; trucks discovered dynamically via `+/telemetry`.
- Red/orange threshold lines at 12 cm (stop) and 20 cm (slow) on every subplot.
- Rolling window of 60 readings; updates every 200 ms.

## 2026-03-19 — Visualization real-time path fix (ajuan)
- Rewrote `run_visualizer()` and `TruckState` in `map_visualization.py`:
  - Added incremental axis bounds tracking (`_expand_bounds`) — O(1) per message, O(trucks) per frame instead of O(points).
  - Fixed wall scatter: initialised with `np.empty((0,2))` so `set_offsets` is safe from the first frame.
  - Added filled dot for current truck position.
  - Boundary rectangle label colour changed to red to match rect.
  - Path line clearly dashed, all artists update correctly each frame.

## 2026-03-19 — Visualizer & simulator UX fixes (ajuan)
- `map_visualization.py`: boundary rectangle now always rendered in red; path line changed to dashed.
- `truck_simulator.py`: truck starts at random position ≥20 cm from any border (`START_MARGIN = 20.0`).
- `truck_simulator.py`: position printed every 5 seconds with `[POS]` prefix.
- Task closed.

## 2026-03-19 — MapClient bootstrap (ajuan)
- Created `truck_simulator.py`: 2-D field simulator publishing MQTT telemetry.
  - `ReactiveExplore` strategy: simple obstacle-avoidance.
  - `EmbeddedExplore` strategy: mirrors ESP32 `z_main_control_loop.cpp` exactly (EMA filter, corridor centering, hysteresis, timed recovery).
  - Field set to 120 × 240 cm.
  - `--strategy` CLI flag to select strategy at runtime.
- Created `map_visualization.py`: real-time MQTT subscriber + matplotlib visualizer.
  - Wildcard subscription `+/telemetry` discovers all trucks dynamically.
  - Dead-reckons position or uses ground-truth x/y from simulator payload.
  - Projects sensor rays to collect wall-hit points; fits estimated bounding rectangle.
  - Logs all incoming messages to stdout.
- Created `AGENTS.md` context workflow file for MapClient.
- Bootstrapped `.context/` infrastructure: GUARDRAILS, ARCHITECTURE, STATE, PLAN, TASK, PROJECT_HISTORY, TOOLS, ILLUSTRATION_FORMAT, resources.
- Created `CONFLICTS.md`, `BACKLOG.md`, `DECISIONS.md`.

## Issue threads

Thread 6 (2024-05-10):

Protect ALL critical sections

quarc2000, 2024-05-10:
Currently the code assumes only one task is using a certain resource, and that works as long as we do not switch on preemption. If/when we do we will get many random and difficult to track errors and crashes as device operations might be interrupted in the middle and then continued after a different context. The obvious one here is the i2c port that should be protected against this also if we use timers or do complex GPIO stuff (none atomic operations) these needs to be protected. It is probably a good way of writing wrappers for all the needed functions and have them manage the semaphores to hide it from users, and amke it easy to scan code for any direct use (erroe) of these functions.

quarc2000, 2024-05-10:
And I should add, If an interrupt routie meddles with a davice also used direct by the code (in any task) that will also mess things up.

quarc2000, 2024-05-10:
Comment from Copilot:

Yes, in FreeRTOS, you are allowed to set (give) or release (take) a semaphore from an interrupt service routine (ISR). [The function xSemaphoreGiveFromISR() is specifically designed for this purpose](https://www.freertos.org/a00124.html)[1](https://www.freertos.org/a00124.html).

Here’s an example of how you might use it:
void vAnISR(void)
{
    BaseType_t xHigherPriorityTaskWoken = pdFALSE;

    /* 'Give' the semaphore to unblock the task. */
    xSemaphoreGiveFromISR(xSemaphore, &xHigherPriorityTaskWoken);

    /* If giving the semaphore unblocked a task, and the unblocked task has
    a priority that is higher than the currently running task, then
    xHigherPriorityTaskWoken will have been set to pdTRUE.  If
    xHigherPriorityTaskWoken is pdTRUE then a context switch should be
    requested. */
    portYIELD_FROM_ISR(xHigherPriorityTaskWoken);
}

In this example, xSemaphore is the handle to the semaphore being released. [This is the handle returned when the semaphore was created](https://www.freertos.org/a00124.html)[1](https://www.freertos.org/a00124.html).

[Please note that mutex type semaphores (those created using a call to xSemaphoreCreateMutex()) must not be used with this macro](https://www.freertos.org/a00124.html)[1](https://www.freertos.org/a00124.html). [Also, remember to handle the xHigherPriorityTaskWoken parameter correctly to ensure that a context switch occurs if a higher priority task was unblocked](https://www.freertos.org/a00124.html)[1](https://www.freertos.org/a00124.html).

teddycool, 2025-02-01:
The patterns with semaphores will be used in the new main.

Closed 2025-02-01.

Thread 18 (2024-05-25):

Hardware version 3

teddycool, 2024-05-25:
Design a new hardware using KiCAD.

**Suggested upgrades from version 2:**
- Add connection for a buck/boost voltage regulator to always have a good 5V to the US sensors
- Add a cmos-ttl level shifting circuit for the echo signals
- Use an analog input to measure the battery voltage level
- Use more robust contacts for the motors

Please feel free to suggest more upgrades in the comments

teddycool, 2025-02-01:
The electrical design for the new hardware including the PCB is found here: https://github.com/teddycool/atmt/tree/main/hw/pcb-kicad/atmt-kcad

As soon as I have tried it out I will create a link to www.aisler.net to order the board

Closed 2025-02-01.

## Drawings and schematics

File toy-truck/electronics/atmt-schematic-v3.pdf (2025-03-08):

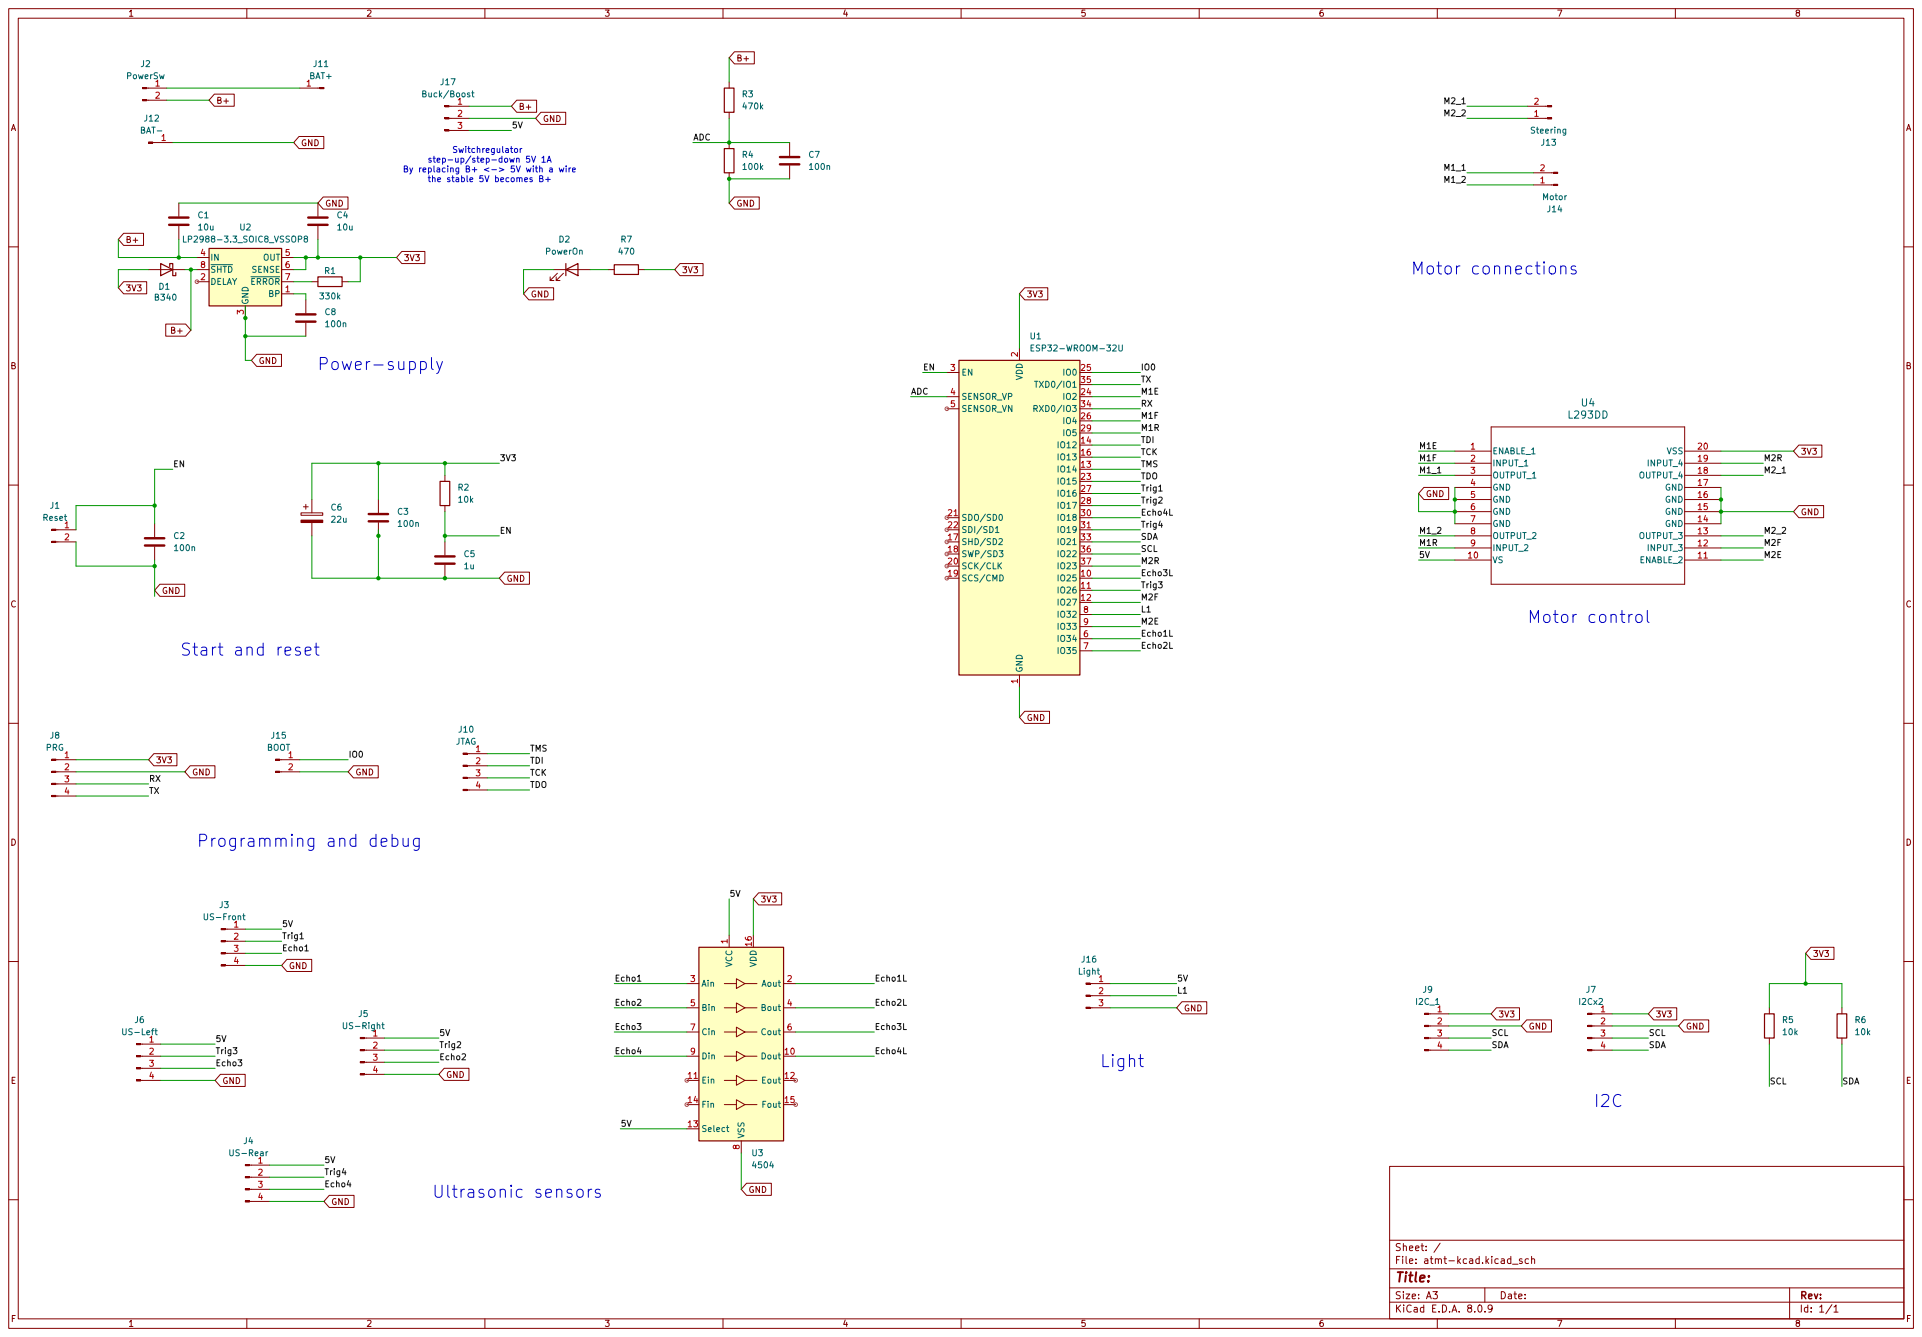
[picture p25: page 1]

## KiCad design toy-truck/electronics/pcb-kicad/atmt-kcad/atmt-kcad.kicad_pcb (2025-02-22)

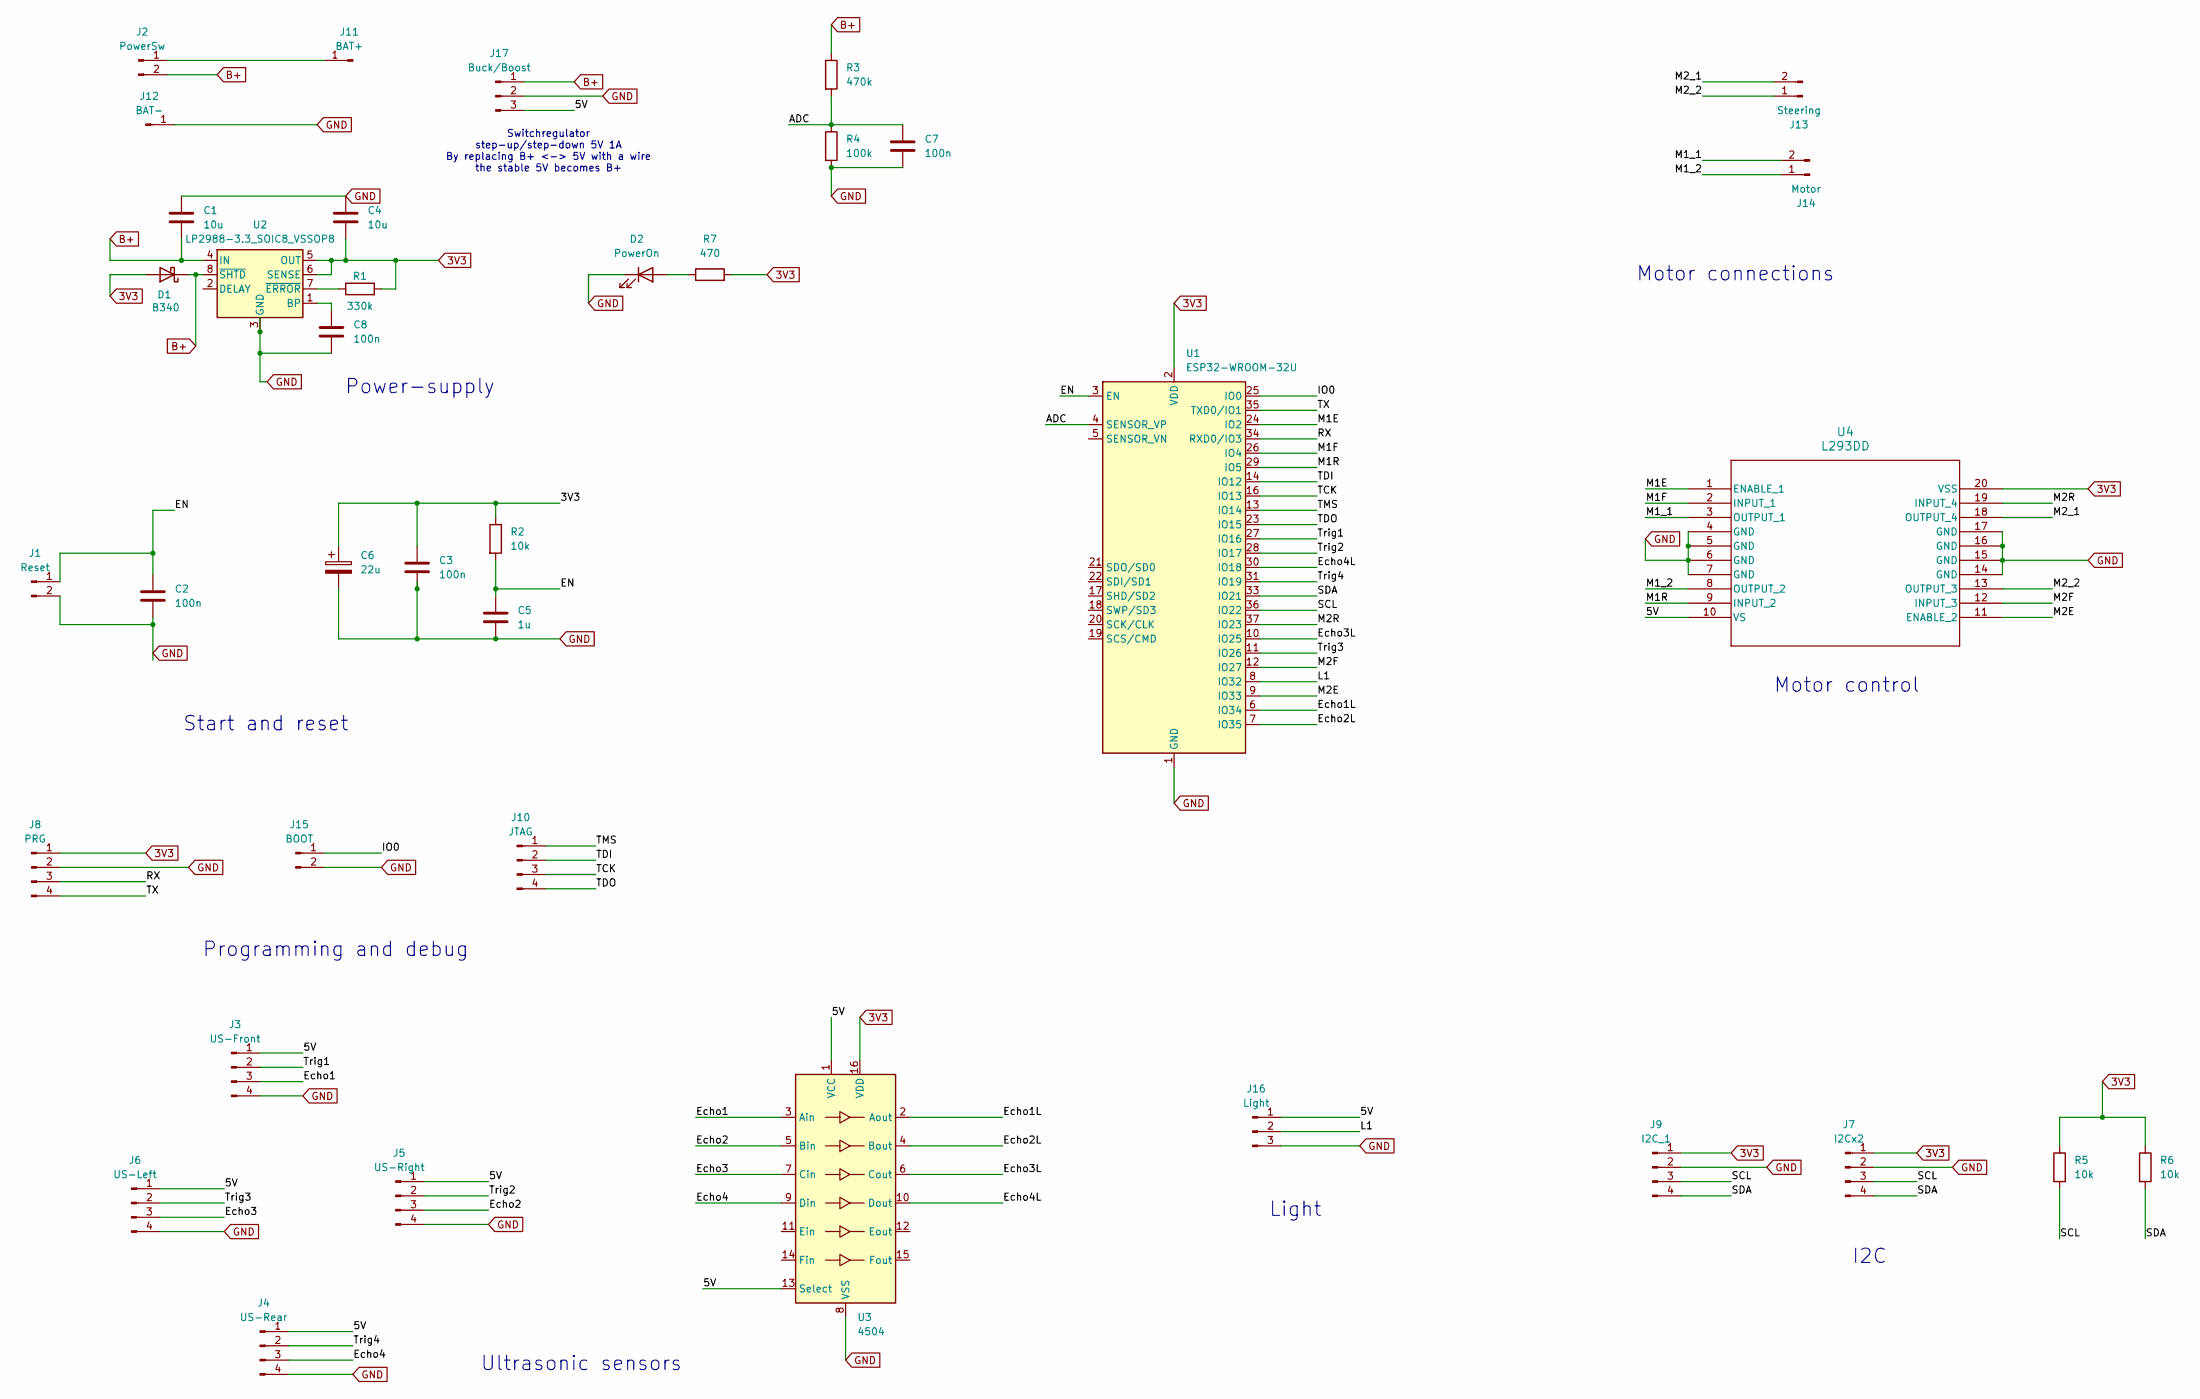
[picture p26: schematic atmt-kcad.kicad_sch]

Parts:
C1, C4: 10u; C_0805_2012Metric_Pad1.18x1.45mm_HandSolder
C2, C3, C7, C8: 100n; C_0805_2012Metric_Pad1.18x1.45mm_HandSolder
C5: 1u; C_0805_2012Metric_Pad1.18x1.45mm_HandSolder
C6: 22u; CP_Radial_D5.0mm_P2.00mm
D1: B340; D_SMC
D2: PowerOn; LED_D3.0mm
J1: Reset; PinHeader_1x02_P2.54mm_Vertical
J2: PowerSw; PinHeader_1x02_P2.54mm_Vertical
J3: US-Front; PinHeader_1x04_P2.54mm_Vertical
J4: US-Rear; PinHeader_1x04_P2.54mm_Vertical
J5: US-Right; PinHeader_1x04_P2.54mm_Vertical
J6: US-Left; PinHeader_1x04_P2.54mm_Vertical
J7: I2Cx2; PinHeader_1x04_P2.54mm_Vertical
J8: PRG; PinHeader_1x04_P2.54mm_Vertical
J9: I2C_1; PinHeader_1x04_P2.54mm_Vertical
J10: JTAG; PinHeader_1x04_P2.54mm_Vertical
J11: BAT+; SolderWire-1.5sqmm_1x01_D1.7mm_OD3mm
J12: BAT-; SolderWire-1.5sqmm_1x01_D1.7mm_OD3mm
J13: Steering; PhoenixContact_MSTBA_2,5_2-G-5,08_1x02_P5.08mm_Horizontal
J14: Motor; PhoenixContact_MSTBA_2,5_2-G-5,08_1x02_P5.08mm_Horizontal
J15: BOOT; PinHeader_1x02_P2.54mm_Vertical
J16: Light; PinHeader_1x03_P2.54mm_Vertical
J17: Buck/Boost; PinHeader_1x03_P2.54mm_Vertical
R1: 330k; R_0805_2012Metric_Pad1.20x1.40mm_HandSolder
R2, R5, R6: 10k; R_0805_2012Metric_Pad1.20x1.40mm_HandSolder
R3: 470k; R_0805_2012Metric_Pad1.20x1.40mm_HandSolder
R4: 100k; R_0805_2012Metric_Pad1.20x1.40mm_HandSolder
R7: 470; R_0805_2012Metric_Pad1.20x1.40mm_HandSolder
U1: ESP32-WROOM-32U
U2: LP2988-3.3_SOIC8_VSSOP8; SOIC-8_3.9x4.9mm_P1.27mm
U3: 4504; SOIC-16_3.9x9.9mm_P1.27mm
U4: L293DD; SO-20_STM

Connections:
3V3: C3.1, C4.2, C6.1, D1.2 (A), J7.1, J8.1, J9.1, R1.2, R2.1, R5.1, R6.1, R7.2, U1.2 (VDD), U2.5 (OUT), U2.6 (SENSE), U3.16 (VDD), U4.20 (VSS)
/5V: J3.1, J4.1, J5.1, J6.1, J16.1, J17.3, U3.1 (VCC), U3.13 (Select), U4.10 (VS)
/ADC: C7.1, R3.2, R4.1, U1.4 (SENSOR_VP)
/EN: C2.1, C5.1, J1.1, R2.2, U1.3 (EN)
/Echo1: J3.3, U3.3 (Ain)
/Echo1L: U1.6 (IO34), U3.2 (Aout)
/Echo2: J5.3, U3.5 (Bin)
/Echo2L: U1.7 (IO35), U3.4 (Bout)
/Echo3: J6.3, U3.7 (Cin)
/Echo3L: U1.10 (IO25), U3.6 (Cout)
/Echo4: J4.3, U3.9 (Din)
/Echo4L: U1.30 (IO18), U3.10 (Dout)
/IO0: J15.1, U1.25 (IO0)
/L1: J16.2, U1.8 (IO32)
/M1E: U1.24 (IO2), U4.1 (ENABLE_1)
/M1F: U1.26 (IO4), U4.2 (INPUT_1)
/M1R: U1.29 (IO5), U4.9 (INPUT_2)
/M1_1: J14.2, U4.3 (OUTPUT_1)
/M1_2: J14.1, U4.8 (OUTPUT_2)
/M2E: U1.9 (IO33), U4.11 (ENABLE_2)
/M2F: U1.12 (IO27), U4.12 (INPUT_3)
/M2R: U1.37 (IO23), U4.19 (INPUT_4)
/M2_1: J13.2, U4.18 (OUTPUT_4)
/M2_2: J13.1, U4.13 (OUTPUT_3)
/RX: J8.3, U1.34 (RXD0/IO3)
/SCL: J7.3, J9.3, R5.2, U1.36 (IO22)
/SDA: J7.4, J9.4, R6.2, U1.33 (IO21)
/TCK: J10.3, U1.16 (IO13)
/TDI: J10.2, U1.14 (IO12)
/TDO: J10.4, U1.23 (IO15)
/TMS: J10.1, U1.13 (IO14)
/TX: J8.4, U1.35 (TXD0/IO1)
/Trig1: J3.2, U1.27 (IO16)
/Trig2: J5.2, U1.28 (IO17)
/Trig3: J6.2, U1.11 (IO26)
/Trig4: J4.2, U1.31 (IO19)
B+: C1.2, D1.1 (K), J2.2, J17.1, R3.1, U2.4 (IN), U2.8 (~SHTD)
GND: C1.1, C2.2, C3.2, C4.1, C5.2, C6.2, C7.2, C8.2, D2.1 (K), J1.2, J3.4, J4.4, J5.4, J6.4, J7.2, J8.2, J9.2, J12.1, J15.2, J16.3, J17.2, R4.2, U1.1 (GND), U1.15 (GND), U1.38 (GND), U1.39 (GND), U2.3 (GND), U3.8 (VSS), U4.4 (GND), U4.5 (GND), U4.6 (GND), U4.7 (GND), U4.14 (GND), U4.15 (GND), U4.16 (GND), U4.17 (GND)
unnamed: D2.2 (A), R7.1
unnamed: J2.1, J11.1
unnamed: C8.1, U2.1 (BP)
unnamed: R1.1, U2.7 (~ERROR)

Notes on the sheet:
Motor control
Switchregulator step-up/step-down 5V 1A By replacing B+ <-> 5V with a wire the stable 5V becomes B+
Programming and debug
Motor connections
Light
I2C
Start and reset
Power-supply
Ultrasonic sensors

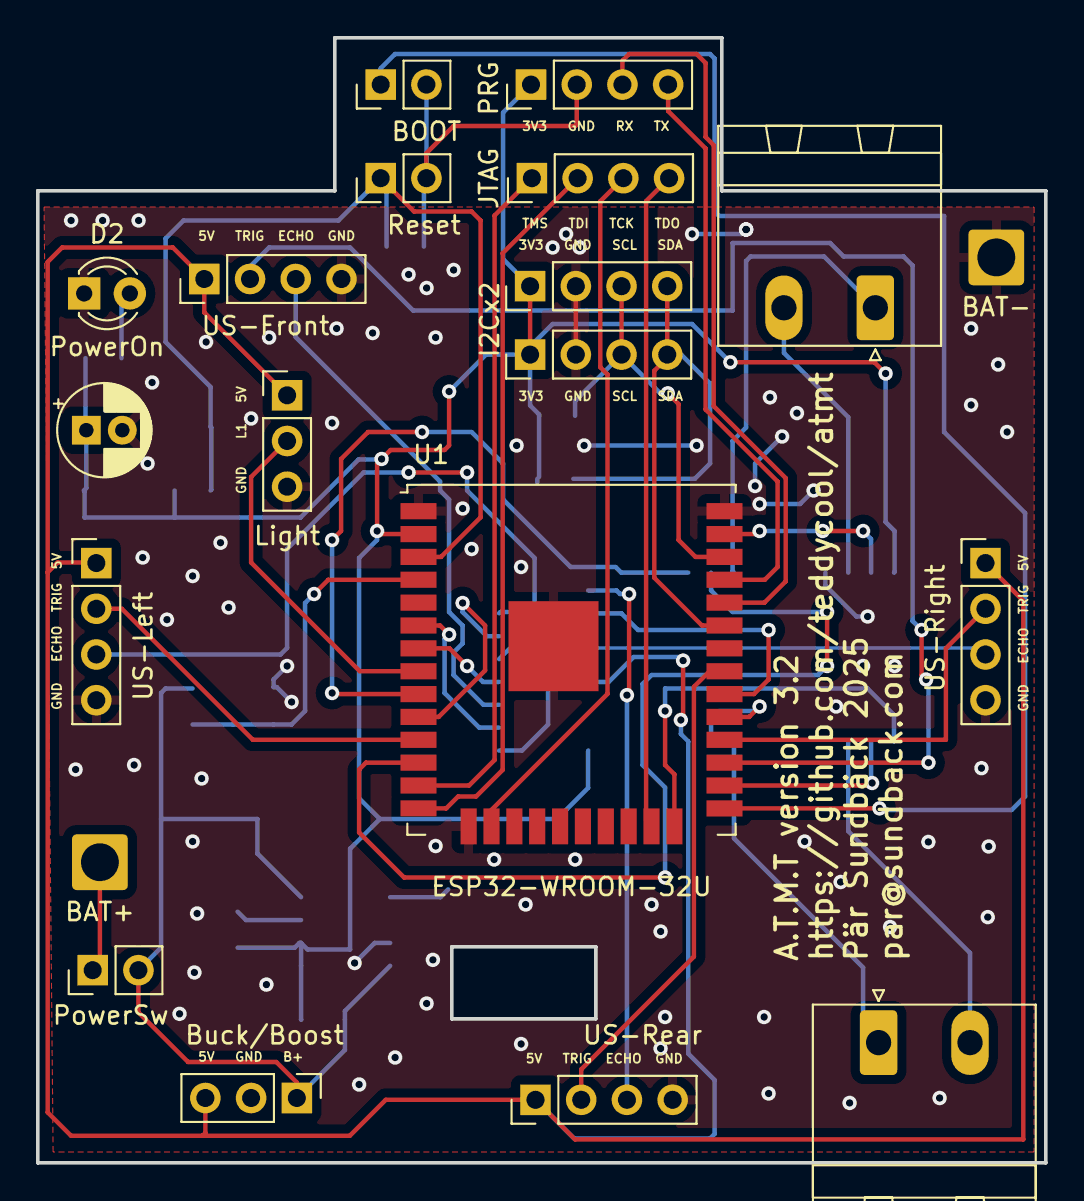
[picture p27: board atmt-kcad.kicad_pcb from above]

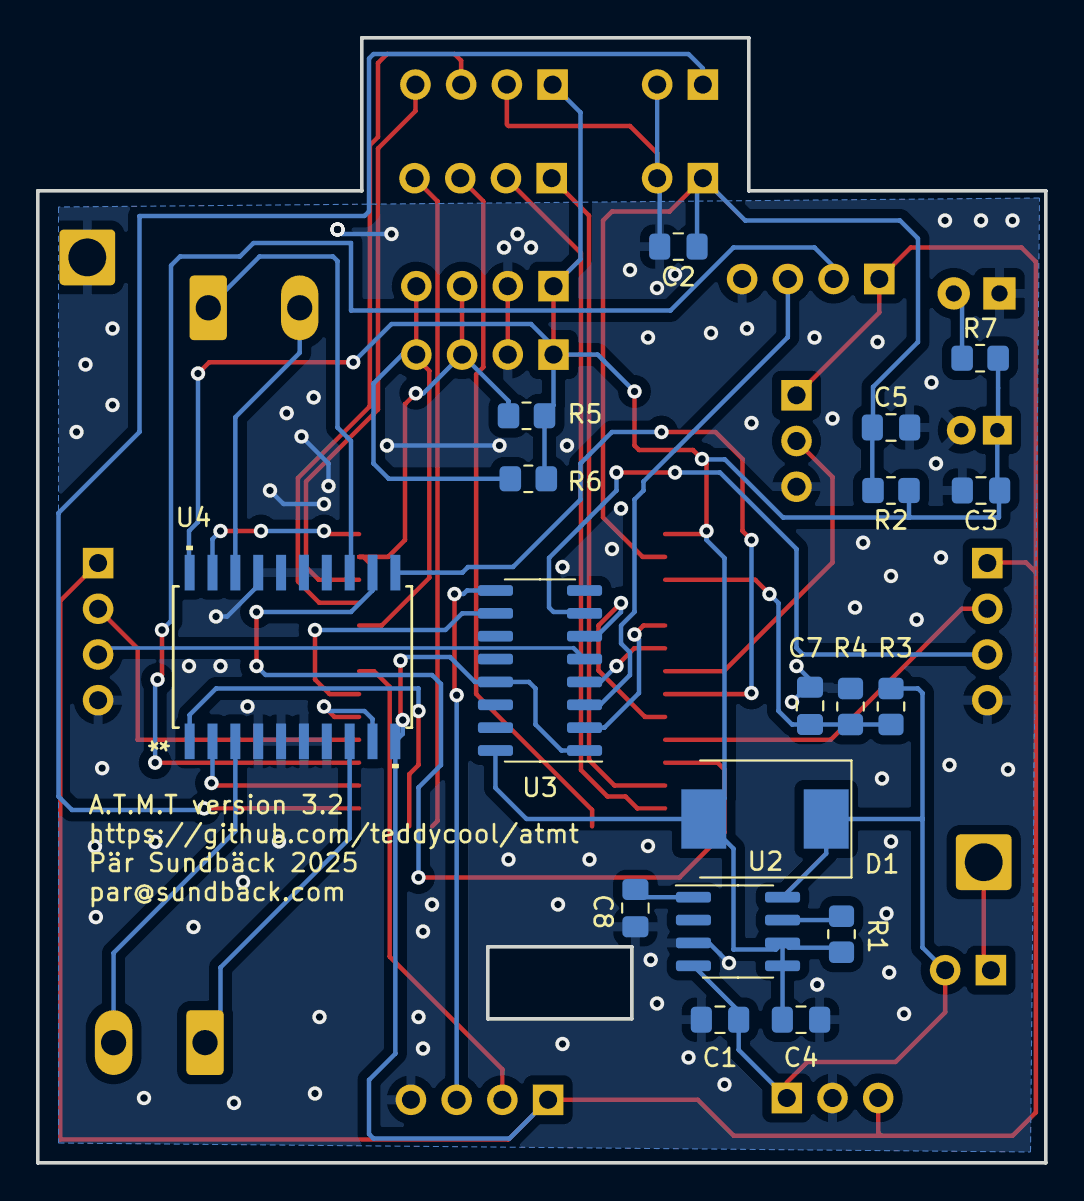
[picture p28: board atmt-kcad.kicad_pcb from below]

Board: 2 copper layers, 56.0 x 62.5 mm, 38 parts (18 on the bottom side), 42 nets.

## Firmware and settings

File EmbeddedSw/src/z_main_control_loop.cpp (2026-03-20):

// Minimal exploration controller skeleton for an ESP32-based truck
// Purpose:
// - Read filtered sensor values
// - Run a simple state machine: IDLE / EXPLORE / RECOVER / STOP
// - Apply basic wall-centering + obstacle avoidance
// - Publish telemetry periodically
#include <Arduino.h>
#include <WiFi.h>
#include <ArduinoOTA.h>
#include <stdarg.h>
#include <math.h>
#include "esp_system.h"
#include "esp_task_wdt.h"
#include "soc/soc.h"
#include "soc/rtc_cntl_reg.h"
#include "esp_bt.h"
#include <variables/setget.h>
#include <sensors/usensor.h>
#include <sensors/accsensor.h>
#include <sensors/compass.h>
#include <actuators/motor.h>
#include <actuators/steer.h>
#include <telemetry/mqtt.h>
#include <secrets.h>
#include <atmio.h>

// Global objects
Usensor ultraSound;
ACCsensor accelSensor;
Compass compass;
Motor motor;
Steer steer;
Mqtt mqtt;

char chipId[17];  // Fixed size char array for chip ID (16 hex chars + null terminator)
long int age;

// -----------------------------
// Configuration
// -----------------------------
enum class RunMode {
  REAL,     // Minimal serial output for production
  DEBUG     // Full serial output for development
};

struct ControlConfig {
  // Distances in cm
  float frontStopDist = 20.0f;
  float sideMinDist   = 6.0f;

  // Corridor-centering
  float centerDeadband = 3.0f;     // |UR - UL| below this => go straight
  uint8_t steerHoldSamples = 3;    // hysteresis before changing steering

  // PWM
  int pwmExplore = 95;
  int pwmSlow    = 95;
  int pwmReverse = -95;

  // Timing
  uint32_t telemetryPeriodMs = 500;  // 1 Hz to reduce heap pressure
  uint32_t recoverReverseMs  = 1500;
  uint32_t recoverTurnMs     = 1000;
  uint32_t stuckFrontMs      = 500;

  // Filtering
  float usAlpha = 0.35f;          // exponential smoothing factor
  float imuAlpha = 0.25f;
  
  // Run mode
  RunMode runMode = RunMode::REAL;  // Set to REAL for production
};

ControlConfig cfg;

// -----------------------------
// Basic types
// -----------------------------
enum class Mode {
  IDLE,
  EXPLORE,
  RECOVER,
  STOP
};

enum class SteerCmd {
  LEFT,
  STRAIGHT,
  RIGHT
};

struct RawSensors {
  float ul = NAN;       // ultrasonic left
  float ur = NAN;       // ultrasonic right
  float uf = NAN;       // ultrasonic front
  float ub = NAN;       // ultrasonic back
  float yawRate = NAN;  // deg/s
  float gyX = NAN;      // gyro X
  float gyY = NAN;      // gyro Y
  float gyZ = NAN;      // gyro Z
  float heading = NAN;  // deg
  // Compass values
  float magX = NAN;     // magnetic field X
  float magY = NAN;     // magnetic field Y
  float magZ = NAN;     // magnetic field Z
  float compass = NAN;  // calculated compass heading
  // Accelerometer values
  float accX = NAN;     // acceleration X
  float accY = NAN;     // acceleration Y
  float accZ = NAN;     // acceleration Z
};

struct FilteredSensors {
  float ul = NAN;
  float ur = NAN;
  float uf = NAN;
  float ub = NAN;
  float yawRate = NAN;
  float gyX = NAN;
  float gyY = NAN;
  float gyZ = NAN;
  float heading = NAN;
  // Compass values
  float magX = NAN;
  float magY = NAN;
  float magZ = NAN;
  float compass = NAN;
  // Accelerometer values
  float accX = NAN;
  float accY = NAN;
  float accZ = NAN;
};

struct Features {
  float width = NAN;         // ul + ur
  float centerError = NAN;   // ur - ul
  bool frontBlocked = false;
  bool rearBlocked = false;
  bool narrow = false;
};

struct Command {
  int motorPwm = 0;                  // negative = reverse
  SteerCmd steer = SteerCmd::STRAIGHT;
};

struct TelemetryFrame {
  uint32_t seq = 0;
  uint32_t tMs = 0;
  Mode mode = Mode::IDLE;

  RawSensors raw;
  FilteredSensors filt;
  Features feat;
  Command cmd;
};

// -----------------------------
// Global state
// -----------------------------
Mode g_mode = Mode::IDLE;
Command g_cmd;

RawSensors g_raw;
FilteredSensors g_filt;
Features g_feat;

uint32_t g_seq = 0;
uint32_t g_lastTelemetryMs = 0;
uint32_t g_lastMqttStatusMs = 0;  // Add MQTT status reporting timer
uint32_t g_frontBlockedSinceMs = 0;
uint32_t g_recoverStartMs = 0;

SteerCmd g_lastRequestedSteer = SteerCmd::STRAIGHT;
SteerCmd g_appliedSteer = SteerCmd::STRAIGHT;
uint8_t g_sameSteerCount = 0;

// -----------------------------
// Helpers
// -----------------------------
static void debugPrint(const String& message) {
  if (cfg.runMode == RunMode::DEBUG) {
    Serial.println(message);
  }
}

static void debugPrintf(const char* format, ...) {
  if (cfg.runMode == RunMode::DEBUG) {
    va_list args;
    va_start(args, format);
    Serial.printf(format, args);
    va_end(args);
  }
}

static float ema(float prev, float current, float alpha) {
  if (isnan(prev)) return current;
  if (isnan(current)) return prev;
  return alpha * current + (1.0f - alpha) * prev;
}

static const char* modeToString(Mode m) {
  switch (m) {
    case Mode::IDLE:    return "IDLE";
    case Mode::EXPLORE: return "EXPLORE";
    case Mode::RECOVER: return "RECOVER";
    case Mode::STOP:    return "STOP";
    default:            return "UNKNOWN";
  }
}

static const char* steerToString(SteerCmd s) {
  switch (s) {
    case SteerCmd::LEFT:     return "LEFT";
    case SteerCmd::STRAIGHT: return "STRAIGHT";
    case SteerCmd::RIGHT:    return "RIGHT";
    default:                 return "UNKNOWN";
  }
}

// -----------------------------
// Hardware abstraction stubs
// Replace these with your real implementations
// -----------------------------
float readUltrasonicLeftCm()   { 
  long val = globalVar_get(rawDistLeft, &age); 
  return (float)val;
}
float readUltrasonicRightCm()  { 
  long val = globalVar_get(rawDistRight, &age); 
  return (float)val;
}
float readUltrasonicFrontCm()  { 
  long val = globalVar_get(rawDistFront, &age); 
  return (float)val;
}
float readUltrasonicBackCm()   { 
  long val = globalVar_get(rawDistBack, &age); 
  return (float)val;
}
float readYawRateDegPerSec()   { 
  // Convert raw gyro Z to deg/s (divide by 131 for MPU6050)
  long raw = globalVar_get(rawGyZ, &age);
  return raw / 131.0f;
}
float readGyroX() {
  long raw = globalVar_get(rawGyX, &age);
  return (float)raw;
}
float readGyroY() {
  long raw = globalVar_get(rawGyY, &age);
  return (float)raw;
}
float readGyroZ() {
  long raw = globalVar_get(rawGyZ, &age);
  return (float)raw;
}
float readHeadingDeg()         { 
  // Get calculated heading from compass (in 1/10 degrees)
  long heading = globalVar_get(calcHeading, &age);
  if (heading == -1) {
    return NAN; // Invalid heading from compass task
  }
  return heading / 10.0f;
}

float readMagneticX() {
  long val = globalVar_get(rawMagX, &age);
  return (float)val;
}

float readMagneticY() {
  long val = globalVar_get(rawMagY, &age);
  return (float)val;
}

float readMagneticZ() {
  long val = globalVar_get(rawMagZ, &age);
  return (float)val;
}

float readAccelerationX() {
  long val = globalVar_get(rawAccX, &age);
  return (float)val;
}

float readAccelerationY() {
  long val = globalVar_get(rawAccY, &age);
  return (float)val;
}

float readAccelerationZ() {
  long val = globalVar_get(rawAccZ, &age);
  return (float)val;
}

void setMotorPwm(int pwm) {
  // Map signed PWM to motor driver direction + duty cycle
  // PWM range: -100 (full reverse) to +100 (full forward)
  int clampedPwm = constrain(pwm, -100, 100);
  motor.driving(clampedPwm);
}

void setSteering(SteerCmd steerCmd) {
  // Control steering hardware based on command
  switch (steerCmd) {
    case SteerCmd::LEFT:
      steer.Left();
      break;
    case SteerCmd::RIGHT:
      steer.Right();
      break;
    case SteerCmd::STRAIGHT:
    default:
      steer.Straight();
      break;
  }
}

bool mqttConnected() {
  return mqtt.connected();
}

void mqttLoop() {
  // MQTT with enhanced thread safety
  if (ESP.getFreeHeap() < 6000) {
    return; // Skip MQTT when low memory
  }
  
  try {
    mqtt.loop();
  } catch (...) {
    // Ignore MQTT errors to prevent crashes
  }
  yield();
}

void publishTelemetry(const TelemetryFrame& t) {
  // MQTT publishing with enhanced safety
  if (!mqttConnected()) {
    return;  // Silent fail
  }
  
  // Check memory before proceeding
  if (ESP.getFreeHeap() < 8000) {
    return;  // Silent fail on low memory
  }
  
  yield();
  
  // Check chipId is valid before using it
  if (strlen(chipId) == 0) {
    uint64_t chipIdHex = ESP.getEfuseMac();
    snprintf(chipId, sizeof(chipId), "%x", (uint32_t)chipIdHex);
  }
  
  // Use static buffer to prevent any heap allocation
  static char jsonStr[512];  // Increased to fit full telemetry payload
  memset(jsonStr, 0, sizeof(jsonStr));  // Clear buffer completely
  
  int written = snprintf(jsonStr, sizeof(jsonStr),
    "{"
    "\"truck_id\":\"%s\","
    "\"seq\":%u,"
    "\"t_ms\":%lu,"
    "\"mode\":\"%s\","
    "\"ul\":%.1f,"
    "\"ur\":%.1f,"
    "\"uf\":%.1f,"
    "\"ub\":%.1f,"
    "\"yaw_rate\":%.2f,"
    "\"gy_x\":%.2f,"
    "\"gy_y\":%.2f,"
    "\"gy_z\":%.2f,"
    "\"heading\":%.1f,"
    "\"compass\":%.1f,"
    "\"mag_x\":%.2f,"
    "\"mag_y\":%.2f,"
    "\"mag_z\":%.2f,"
    "\"acc_x\":%.2f,"
    "\"acc_y\":%.2f,"
    "\"acc_z\":%.2f,"
    "\"width\":%.1f,"
    "\"center_error\":%.1f,"
    "\"front_blocked\":%s,"
    "\"cmd_pwm\":%d,"
    "\"cmd_steer\":\"%s\""
    "}",
    chipId, (unsigned)t.seq, (unsigned long)t.tMs, modeToString(t.mode),
    t.filt.ul, t.filt.ur, t.filt.uf, t.filt.ub,
    t.filt.yawRate, t.filt.gyX, t.filt.gyY, t.filt.gyZ,
    t.filt.heading, t.filt.compass,
    t.filt.magX, t.filt.magY, t.filt.magZ,
    t.filt.accX, t.filt.accY, t.filt.accZ,
    t.feat.width, t.feat.centerError,
    t.feat.frontBlocked ? "true" : "false",
    t.cmd.motorPwm, steerToString(t.cmd.steer)
  );
  
  // Safety check - ensure we didn't overflow buffer
  if (written >= sizeof(jsonStr)) {
    return; // Skip this telemetry if too large
  }
  
  // Publish with basic error checking
  if (mqttConnected() && ESP.getFreeHeap() > 6000) {
    mqtt.send("telemetry", jsonStr);
  }
  yield();
}

void filterSensors(const RawSensors& raw, FilteredSensors& filt) {
  filt.ul = ema(filt.ul, raw.ul, cfg.usAlpha);
  filt.ur = ema(filt.ur, raw.ur, cfg.usAlpha);
  filt.uf = ema(filt.uf, raw.uf, cfg.usAlpha);
  filt.ub = ema(filt.ub, raw.ub, cfg.usAlpha);

  filt.yawRate = ema(filt.yawRate, raw.yawRate, cfg.imuAlpha);
  filt.gyX = ema(filt.gyX, raw.gyX, cfg.imuAlpha);
  filt.gyY = ema(filt.gyY, raw.gyY, cfg.imuAlpha);
  filt.gyZ = ema(filt.gyZ, raw.gyZ, cfg.imuAlpha);
  filt.heading = ema(filt.heading, raw.heading, cfg.imuAlpha);
  
  // Filter compass values
  filt.magX = ema(filt.magX, raw.magX, cfg.imuAlpha);
  filt.magY = ema(filt.magY, raw.magY, cfg.imuAlpha);
  filt.magZ = ema(filt.magZ, raw.magZ, cfg.imuAlpha);
  // Compass is same as heading now
  filt.compass = filt.heading;
  
  // Filter accelerometer values
  filt.accX = ema(filt.accX, raw.accX, cfg.imuAlpha);
  filt.accY = ema(filt.accY, raw.accY, cfg.imuAlpha);
  filt.accZ = ema(filt.accZ, raw.accZ, cfg.imuAlpha);
}

void deriveFeatures(const FilteredSensors& filt, Features& feat) {
  feat.width = filt.ul + filt.ur;
  feat.centerError = filt.ur - filt.ul;

  feat.frontBlocked = !isnan(filt.uf) && filt.uf < cfg.frontStopDist;
  feat.rearBlocked  = !isnan(filt.ub) && filt.ub < cfg.frontStopDist;
  feat.narrow = !isnan(feat.width) && feat.width < 22.0f;  // tune for your track
}

// -----------------------------
// Steering hysteresis
// -----------------------------
SteerCmd requestSteerWithHysteresis(SteerCmd requested) {
  if (requested == g_lastRequestedSteer) {
    if (g_sameSteerCount < 255) g_sameSteerCount++;
  } else {
    g_lastRequestedSteer = requested;
    g_sameSteerCount = 1;
  }

  if (g_sameSteerCount >= cfg.steerHoldSamples) {
    g_appliedSteer = requested;
  }

  return g_appliedSteer;
}

// -----------------------------
// Controller logic
// -----------------------------
Command computeExploreCommand(const Features& feat, const FilteredSensors& filt) {
  Command cmd;
  cmd.motorPwm = cfg.pwmExplore;
  cmd.steer = SteerCmd::STRAIGHT;

  // Front safety
  if (!isnan(filt.uf) && filt.uf < cfg.frontStopDist) {
    cmd.motorPwm = 0;

    // Turn away from the closer wall
    if (filt.ul < filt.ur) {
      cmd.steer = SteerCmd::RIGHT;
    } else {
      cmd.steer = SteerCmd::LEFT;
    }
    return cmd;
  }

  // Corridor-centering
  if (!isnan(feat.centerError)) {
    if (feat.centerError > cfg.centerDeadband) {
      // Right side farther away => truck is biased left => steer right
      cmd.steer = SteerCmd::RIGHT;
    } else if (feat.centerError < -cfg.centerDeadband) {
      cmd.steer = SteerCmd::LEFT;
    } else {
      cmd.steer = SteerCmd::STRAIGHT;
    }
  }

  // Extra safety if too close to side
  if (!isnan(filt.ul) && filt.ul < cfg.sideMinDist) {
    cmd.steer = SteerCmd::RIGHT;
    cmd.motorPwm = cfg.pwmSlow;
  }
  if (!isnan(filt.ur) && filt.ur < cfg.sideMinDist) {
    cmd.steer = SteerCmd::LEFT;
    cmd.motorPwm = cfg.pwmSlow;
  }

  cmd.steer = requestSteerWithHysteresis(cmd.steer);
  return cmd;
}

Command computeRecoverCommand(const Features& feat, const FilteredSensors& filt, uint32_t nowMs) {
  Command cmd;

  // If something is behind us, skip reversing and go to the turn step
  uint32_t dt = nowMs - g_recoverStartMs;
  if (feat.rearBlocked) {
    dt = cfg.recoverReverseMs;
  }

  // Step 1: reverse
  if (dt < cfg.recoverReverseMs) {
    cmd.motorPwm = cfg.pwmReverse;
    cmd.steer = SteerCmd::STRAIGHT;
    return cmd;
  }

  // Step 2: turn away from nearest wall
  if (dt < (cfg.recoverReverseMs + cfg.recoverTurnMs)) {
    cmd.motorPwm = cfg.pwmSlow;

    if (filt.ul < filt.ur) {
      cmd.steer = SteerCmd::RIGHT;
    } else {
      cmd.steer = SteerCmd::LEFT;
    }
    return cmd;
  }

  // Recovery finished, return to explore
  g_mode = Mode::EXPLORE;
  cmd.motorPwm = cfg.pwmSlow;
  cmd.steer = SteerCmd::STRAIGHT;
  return cmd;
}

// -----------------------------
// State machine
// -----------------------------
void enterRecover(uint32_t nowMs) {
  g_mode = Mode::RECOVER;
  g_recoverStartMs = nowMs;
}

void updateStateMachine(const Features& feat, const FilteredSensors& filt, uint32_t nowMs) {
  switch (g_mode) {
    case Mode::IDLE:
      // stay idle until you explicitly switch to EXPLORE
      break;

    case Mode::EXPLORE:
      if (feat.frontBlocked) {
        if (g_frontBlockedSinceMs == 0) {
          g_frontBlockedSinceMs = nowMs;
        } else if ((nowMs - g_frontBlockedSinceMs) > cfg.stuckFrontMs) {
          enterRecover(nowMs);
        }
      } else {
        g_frontBlockedSinceMs = 0;
      }
      break;

    case Mode::RECOVER:
      // handled by timer inside computeRecoverCommand()
      break;

    case Mode::STOP:
      break;
  }
}

// -----------------------------
// Command application
// -----------------------------
void applyCommand(const Command& cmd) {
  setSteering(cmd.steer);
  setMotorPwm(cmd.motorPwm);
}

// -----------------------------
// Telemetry
// -----------------------------
void maybePublishTelemetry(uint32_t nowMs) {
  if ((nowMs - g_lastTelemetryMs) < cfg.telemetryPeriodMs) {
    return;
  }
  g_lastTelemetryMs = nowMs;

  TelemetryFrame t;
  t.seq = g_seq++;
  t.tMs = nowMs;
  t.mode = g_mode;
  t.raw = g_raw;
  t.filt = g_filt;
  t.feat = g_feat;
  t.cmd = g_cmd;

  publishTelemetry(t);
}
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
void loop() {
  // STEP 2: GRADUAL SENSOR RESTORATION + MQTT
  static uint32_t counter = 0;
  const uint32_t nowMs = millis();
  
  // Check heap every 1000 iterations
  if (++counter % 1000 == 0) {
    size_t freeHeap = ESP.getFreeHeap();
    Serial.printf("[%u] Heap: %d bytes, millis: %u\n", counter, freeHeap, nowMs);
    
    // Emergency restart if heap is critically low
    if (freeHeap < 3000) {
      Serial.println("[EMERGENCY] Heap critically low, restarting...");
      delay(100);
      ESP.restart();
    }
  }
  
  // Basic OTA handling
  static uint32_t lastOTA = 0;
  if ((nowMs - lastOTA) > 100) {
    lastOTA = nowMs;
    ArduinoOTA.handle();
  }
  yield();
  
  // MQTT loop with enhanced safety
  static uint32_t lastMqttLoop = 0;
  if ((nowMs - lastMqttLoop) > 100) {  // 10Hz MQTT loop
    lastMqttLoop = nowMs;
    if (ESP.getFreeHeap() > 6000) {  // Only if enough memory
      mqttLoop();
    }
  }
  yield();
  
  // Full sensor read + explore mode control
  static uint32_t lastSensorRead = 0;
  if ((nowMs - lastSensorRead) > 50) {  // 20Hz sensors
    lastSensorRead = nowMs;

    if (ESP.getFreeHeap() > 9000) {
      try {
        g_raw.ul = readUltrasonicLeftCm();
        g_raw.ur = readUltrasonicRightCm();
        g_raw.uf = readUltrasonicFrontCm();
        g_raw.ub = readUltrasonicBackCm();
        g_raw.yawRate = readYawRateDegPerSec();
        g_raw.gyX = readGyroX();
        g_raw.gyY = readGyroY();
        g_raw.gyZ = readGyroZ();
        g_raw.heading = readHeadingDeg();
        g_raw.magX = readMagneticX();
        g_raw.magY = readMagneticY();
        g_raw.magZ = readMagneticZ();
        g_raw.compass = g_raw.heading;
        g_raw.accX = readAccelerationX();
        g_raw.accY = readAccelerationY();
        g_raw.accZ = readAccelerationZ();

        filterSensors(g_raw, g_filt);
        deriveFeatures(g_filt, g_feat);

        if (counter % 3000 == 0) {
          Serial.printf("[SENSORS] UL:%.1f UR:%.1f UF:%.1f UB:%.1f\n", g_raw.ul, g_raw.ur, g_raw.uf, g_raw.ub);
        }
      } catch (...) {
        Serial.println("[ERROR] Sensor read failed");
      }
    }
    yield();
  }

  // Auto explore mode
  if (g_mode == Mode::IDLE && nowMs > 2000) {
    g_mode = Mode::EXPLORE;
  }

  updateStateMachine(g_feat, g_filt, nowMs);

  switch (g_mode) {
    case Mode::IDLE:
      g_cmd.motorPwm = 0;
      g_cmd.steer = SteerCmd::STRAIGHT;
      break;
    case Mode::EXPLORE:
      g_cmd = computeExploreCommand(g_feat, g_filt);
      break;
    case Mode::RECOVER:
      g_cmd = computeRecoverCommand(g_feat, g_filt, nowMs);
      break;
    case Mode::STOP:
      g_cmd.motorPwm = 0;
      g_cmd.steer = SteerCmd::STRAIGHT;
      break;
  }

  if (ESP.getFreeHeap() > 4000) {
    applyCommand(g_cmd);
  } else {
    motor.driving(0);
    steer.Straight();
  }
  
  // Publish telemetry at low rate
  static uint32_t lastTelemetry = 0;
  if ((nowMs - lastTelemetry) > 500) {  // 2Hz telemetry
    lastTelemetry = nowMs;
    if (ESP.getFreeHeap() > 8000) {
      // Use minimal telemetry frame
      TelemetryFrame telemetry;
      telemetry.seq = ++g_seq;
      telemetry.tMs = nowMs;
      telemetry.mode = g_mode;
      telemetry.raw = g_raw;
      telemetry.filt = g_filt;
      telemetry.feat = g_feat;
      telemetry.cmd = g_cmd;
      publishTelemetry(telemetry);
    }
  }
  yield();
  
  // Moderate loop speed for stability
  delay(80);  // ~12Hz loop for stability
  yield();
}

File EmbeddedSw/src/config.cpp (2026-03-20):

#include <config.h>

motorType_t motorType;
steerType_t steerType;
boolean servoReverse = false;
int steer_servo_min = 51;
int steer_servo_max = 102;
int steer_servo_adjust = 0;

Config::Config(void) {};

void Config::Begin(void)
{
    Serial.println("-----------------------");
    Serial.println("Configuring truck settings");
    
    // Standard truck configuration
    //motorType = SINGLE;
    //steerType = MOTOR;
    //steer_servo_min = 60;
    //steer_servo_max = 105;
    //steer_servo_adjust = 5;
    // JC Config overwrites default config
    Serial.println("Configures JCA01");
    motorType = DIFFERENTIAL;
    steerType = SERVO;
    steer_servo_min = 60;
    steer_servo_max = 105;
    steer_servo_adjust = 5;
    
    Serial.println("Configuration completed");
};
motorType_t Config::get_motorType(void)
{
    return motorType;
};
steerType_t Config::get_steerType(void)
{
    return steerType;
}

boolean Config::get_servoReverse(void)
{
    return servoReverse;
}

int Config::get_steer_servo_min(void)
{
    return steer_servo_min;
}

int Config::get_steer_servo_max(void)
{
    return steer_servo_max;
}

int Config::get_steer_servo_adjust(void)
{
    return steer_servo_adjust;
}

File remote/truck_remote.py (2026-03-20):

"""
truck_remote.py — Autonomous remote control for the real truck.

Subscribes to the truck telemetry topic, parses sensor data, and publishes
control commands to steer the truck via exploration strategies.

Control interface (from remote.sh)
-----------------------------------
Topic  : {vehicle_id}/control
Payload: {"motor": <-100…100>, "direction": <-100…100>}
  motor     : 100 = full forward, -100 = full reverse, 0 = stop
  direction : -10 = right, 0 = straight, +10 = left (steps of 10)

Strategies
----------
  embedded   — DRIVE/RECOVER state machine (mirrors C++ firmware)
  reactive   — go straight, steer toward open side on obstacle
  wall_right — proportional controller keeping right wall at target distance

Run
---
    python truck_remote.py
    python truck_remote.py --strategy embedded
    python truck_remote.py --broker 192.168.2.2 --id 38504720f540
"""

import argparse
import json
from abc import ABC, abstractmethod

import paho.mqtt.client as mqtt

# ── Configuration ─────────────────────────────────────────────────────────────

MQTT_BROKER = "192.168.2.2"
VEHICLE_ID  = "38504720f540"

TOPIC_TELEMETRY = f"{VEHICLE_ID}/telemetry"
TOPIC_CONTROL   = f"{VEHICLE_ID}/control"

FIELDS = [
    "truck_id", "seq", "t_ms",
    "ul", "ur", "uf", "ub",
    "yaw_rate",
    "heading", "compass",
    "acc_x", "acc_y", "acc_z",
    "cmd_pwm", "cmd_steer",
]

# ── Motor / steering constants ────────────────────────────────────────────────

MOTOR_FWD     = 100    # full forward
MOTOR_REV     = -80    # reverse during recovery
DIR_MAX       = 60     # max direction value
DIR_STEP      = 10     # one steering increment


# ── Parsing ───────────────────────────────────────────────────────────────────

def parse_telemetry(raw: str) -> dict | None:
    try:
        payload = json.loads(raw)
    except json.JSONDecodeError as e:
        print(f"[WARN] JSON parse error: {e}")
        return None

    data = {}
    for field in FIELDS:
        if field not in payload:
            print(f"[WARN] Missing field '{field}' — skipping message")
            return None
        data[field] = payload[field]

    return data


# ── RemoteControl — thin wrapper around send_command ─────────────────────────

class RemoteControl:
    """
    Mirrors the TruckMotion API from the simulator so strategies can be
    ported directly.  Accumulates motor/direction state and publishes via
    send_command() on flush().
    """

    def __init__(self):
        self._motor     = 0
        self._direction = 0

    # Motor — always full power (real truck requires 100 to move)
    def drive_forward(self, pwm: int = 100):
        self._motor = 100

    def drive_reverse(self, pwm: int = 100):
        self._motor = -100

    def stop(self):
        self._motor = 0

    # Steering
    def steer_center(self):
        self._direction = 0

    def steer_left(self):
        self._direction = 60

    def steer_right(self):
        self._direction = -60

    def set_steer(self, value: int):
        """Set direction — positive → 100 (left), negative → -100 (right), 0 → straight."""
        if value > 0:
            self._direction = 60
        elif value < 0:
            self._direction = -60
        else:
            self._direction = 0

    # Publish
    def flush(self, client: mqtt.Client) -> None:
        """Publish the current motor/direction state to the truck."""
        payload = json.dumps({"motor": self._motor, "direction": self._direction})
        client.publish(TOPIC_CONTROL, payload)

    @property
    def motor(self) -> int:
        return self._motor

    @property
    def direction(self) -> int:
        return self._direction


# ── Exploration strategies ────────────────────────────────────────────────────

class ExploreStrategy(ABC):
    """Abstract base — subclasses implement step()."""

    @abstractmethod
    def step(self, sensors: dict, t_ms: int, rc: RemoteControl) -> None:
        """
        Decide control for one telemetry tick.

        Parameters
        ----------
        sensors : dict with keys uf, ub, ul, ur  (cm)
        t_ms    : simulation/truck time in milliseconds
        rc      : RemoteControl object to write motor/steering commands into
        """


class ReactiveExplore(ExploreStrategy):
    """
    Drive forward at full speed.
    When uf < STOP_DIST: stop, steer toward the side with more clearance.
    When uf clears CLEAR_DIST: straighten up and drive forward again.
    """

    STOP_DIST  = 20.0
    CLEAR_DIST = 30.0

    def __init__(self):
        self._avoiding = False

    def step(self, sensors, t_ms, rc):
        uf, ul, ur = sensors["uf"], sensors["ul"], sensors["ur"]

        if self._avoiding:
            if uf >= self.CLEAR_DIST:
                rc.steer_center()
                rc.drive_forward()
                self._avoiding = False
            else:
                rc.drive_reverse(pwm=60)
        else:
            if uf < self.STOP_DIST:
                self._avoiding = True
                rc.stop()
                if ur >= ul:
                    rc.set_steer(-DIR_MAX)   # steer right
                else:
                    rc.set_steer(+DIR_MAX)   # steer left
            else:
                rc.drive_forward()
                rc.steer_center()


class EmbeddedController(ExploreStrategy):
    """
    DRIVE / RECOVER state machine — mirrors the C++ firmware logic.

    DRIVE   : full speed forward, steering centred.
              Transitions to RECOVER when uf < front_stop_dist.
    RECOVER : reverse with max steering toward the open side for
              recover_ms milliseconds, then back to DRIVE.
    """

    def __init__(self,
                 front_stop_dist: float = 20.0,
                 pwm_forward:     int   = 100,
                 pwm_reverse:     int   = 100,
                 recover_ms:      int   = 4000):
        self.front_stop_dist = front_stop_dist
        self.pwm_forward     = pwm_forward
        self.pwm_reverse     = pwm_reverse
        self.recover_ms      = recover_ms

        self._state            = "DRIVE"
        self._recover_start_ms = 0
        self._recover_dir      = +DIR_MAX

    def step(self, sensors, t_ms, rc):
        uf, ul, ur = sensors["uf"], sensors["ul"], sensors["ur"]

        if self._state == "DRIVE":
            if uf < self.front_stop_dist:
                self._recover_dir      = +DIR_MAX if ul < ur else -DIR_MAX
                self._recover_start_ms = t_ms
                self._state            = "RECOVER"
                rc.stop()
            else:
                rc.drive_forward(self.pwm_forward)
                rc.steer_center()

        else:  # RECOVER
            if t_ms - self._recover_start_ms >= self.recover_ms:
                self._state = "DRIVE"
                rc.steer_center()
                rc.drive_forward(self.pwm_forward)
            else:
                rc.set_steer(self._recover_dir)
                rc.drive_reverse(self.pwm_reverse)
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

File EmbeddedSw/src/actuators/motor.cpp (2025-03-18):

#include <Arduino.h>
#include <actuators/motor.h>
#include <config.h>

// Motor 1 (left or both sides if SINGLE motor)
#define ENABLE_ch1_PIN 2
#define FORWARD_ch1_PIN 4
#define REVERSE_ch1_PIN 5

// Motor 2 (right, when DIFFERENTIAL motor)
#define ENABLE_ch2_PIN 33
#define FORWARD_ch2_PIN 27
#define REVERSE_ch2_PIN 23

#define LEFT_MOTOR_PWM_CHANNEL 0
#define RIGHT_MOTOR_PWM_CHANNEL 1
#define MOTOR_PWM_FREQUENCY 5000 // this can be increased later, but hainv an audiable frquency helps the debug phase
                                 // the L293 might be able to handle all the way up to 20000, but 10-12000 should be enough

// motorType_t motorType;

// left or single
uint8_t enable_ch1_pin = 0;
uint8_t forward_ch1_pin = 0;
uint8_t reverse_ch1_pin = 0;

// right when differential
uint8_t enable_ch2_pin = 0;
uint8_t forward_ch2_pin = 0;
uint8_t reverse_ch2_pin = 0;

Config conf;

/*Motor::Motor(uint8_t ena, uint8_t frw, uint8_t rev) : ME(ena), MF(frw), MB(rev){
}*/
Motor::Motor()
{
  conf.Begin();
  motorType = conf.get_motorType();
  switch (motorType)
  {
  case SINGLE:
    // We are using a single motor for propulsion. We will use the first controller channel for that
    //  the first channel will be the LEFT channel when using differential as below
    enable_ch1_pin = ENABLE_ch1_PIN;
    forward_ch1_pin = FORWARD_ch1_PIN;
    reverse_ch1_pin = REVERSE_ch1_PIN;
    // set-up PWM on ENABLE channel, and start with 0 duty cycle

    // set up pins and start with breaks on
    digitalWrite(forward_ch1_pin, LOW);
    digitalWrite(reverse_ch1_pin, LOW);
    pinMode(forward_ch1_pin, OUTPUT);
    pinMode(reverse_ch1_pin, OUTPUT);
    // Initialize motor PWM (5 kHz)
    ledcSetup(LEFT_MOTOR_PWM_CHANNEL, MOTOR_PWM_FREQUENCY, 8); // Channel 0, 5 kHz frequency, 8-bit resolution
    ledcAttachPin(enable_ch1_pin, LEFT_MOTOR_PWM_CHANNEL);     // Attach motorPin to PWM channel 0
    ledcWrite(LEFT_MOTOR_PWM_CHANNEL, 0);
    break;

  case DIFFERENTIAL:
    // we are using separat motors for left and right side, providing more power
    // acting as an electrical differential, and allowing for steering enhancement
    // by also using different throttle on left and right side, both for drive and brake.
    enable_ch1_pin = ENABLE_ch1_PIN;
    forward_ch1_pin = FORWARD_ch1_PIN;
    reverse_ch1_pin = REVERSE_ch1_PIN;
    enable_ch2_pin = ENABLE_ch2_PIN;
    forward_ch2_pin = FORWARD_ch2_PIN;
    reverse_ch2_pin = REVERSE_ch2_PIN;
    // set-up PWM on ENABLE channel, and start with 0 duty cycle

    // set up pins and start with breaks on
    digitalWrite(forward_ch1_pin, LOW);
    digitalWrite(reverse_ch1_pin, LOW);
    pinMode(forward_ch1_pin, OUTPUT);
    pinMode(reverse_ch1_pin, OUTPUT);
    // Initialize motor PWM (5 kHz)
    ledcSetup(LEFT_MOTOR_PWM_CHANNEL, MOTOR_PWM_FREQUENCY, 8); // Channel 0, 5 kHz frequency, 8-bit resolution
    ledcAttachPin(enable_ch1_pin, LEFT_MOTOR_PWM_CHANNEL);     // Attach motorPin to PWM channel 0
    ledcWrite(LEFT_MOTOR_PWM_CHANNEL, 0);

    // set up pins and start with breaks on
    digitalWrite(forward_ch2_pin, LOW);
    digitalWrite(reverse_ch2_pin, LOW);
    pinMode(forward_ch2_pin, OUTPUT);
    pinMode(reverse_ch2_pin, OUTPUT);
    // Initialize motor PWM (5 kHz)
    ledcSetup(RIGHT_MOTOR_PWM_CHANNEL, MOTOR_PWM_FREQUENCY, 8); // Channel 0, 5 kHz frequency, 8-bit resolution
    ledcAttachPin(enable_ch2_pin, RIGHT_MOTOR_PWM_CHANNEL);     // Attach motorPin to PWM channel 0
    ledcWrite(RIGHT_MOTOR_PWM_CHANNEL, 0);

    break;

  default:
    // do not set-up
    break;
  }
}
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

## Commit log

2021-02-07 First filedrop
    [atmt.brd, atmt.sch, body-top-7.stl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]
2021-02-20 first commit of control-sysetm
    [atmt.brd, atmt.sch]
2021-03-24 new board and some code..
    [atmt.brd]
2021-03-25 new board
2021-04-16 new pcb
    [atmt.brd]
2024-04-13 First step for scaniahack
    [body-top.FCStd]
2024-04-13 Updates with circuit diagram
2024-04-28 Major update and clean-up
    [d-sensor-bracket.FCStd, sidebracket.FCStd, sidebracket.stl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]
2024-05-10 Now there should ONLY be my readme file (#3)
    * working version with flashing of leds from two tasks
    * two tasks working
    * typ fungerande version, dock men lite hårdkodat.... Var problem hitta rtos headerfiler så fick lägga till -I i platform.io
    * ok
    * ok test of pralell data from ultrasound
    * Adapted to the toy truck for left and right sensor,
    * stopped tracking many files
    * first commit
    * Deleted old directories and files
    * Delete sw/atm-control-arduino/.vscode/launch.json
    * Delete sw/atm-control-arduino/.vscode/c_cpp_properties.json
2024-05-11 Here we go with some actual code..... (#5)
    * updated README
    * updated README
    * Testocode that includes safe read/write
    ---------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
2024-05-13 Adapted for truck (#8)
    * Working example version for the truck, magnetic sensor par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
2024-05-16 reverse back and forward
    [motor.cpp]
2024-05-16 stop when <20cm from object
2024-05-16 Added steering functions with better restructuring
2024-05-16 Vehicle goes ztright based on gyro feedback (#11)
    * Working example version for the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
2024-05-16 added mqtt measurements logs (#12)
    * added arduino json lib
    * merge repos
    ---------
2024-05-17 invert steering when reverse
2024-05-28 Start of clean-up and restructure
    [atmt-kcad.kicad_pcb, atmt-kcad.kicad_sch, atmt.brd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]
2024-07-05 Before refactoring
    [atmt-kcad.kicad_pcb, atmt-kcad.kicad_sch]
2025-01-31 added pin-descr
    [atmt-kcad.kicad_pcb, atmt-kcad.kicad_sch]
2025-02-01 Examples directory started. (#22)
    * Scacaniahack 2024
    * AI generated example (not yet tested) as how to create different types of tasks.
    * corrected the include paths
    * calssing started. realised it will be very difficult to keep interrupts separate and to avoid the sensors disturb each other. So a redesign wioll be needed. COnstructor to create a table, then you can add sensor by sensor, and then call start. One sensor at a time will then be triggered by the task and it it clear which echo is reveived.
    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
    [usensor.cpp]
2025-02-07 Usensor (#23)
    * Passing compilation for z_main_usensor for the first time. Linking problem, and not yet tested
    * Backup commit
    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
    [usensor.cpp]
2025-02-08 New kicad and a new hello-world-sw
    [atmt-kcad.csv, atmt-kcad.kicad_pcb, atmt-kcad.kicad_sch]
2025-02-08 Seems to be working, Back sensor gives correct numbers, the other not, but could be cable problems (#24)
    [usensor.cpp]
2025-02-08 First working motor control with test pack that runs motor forward and backwards (#25)
    * Seems to be working, Back sensor gives correct numbers, the other not, but could be cable problems
    * First working new motor control. Only drive is implem,ented, breaking can be done later. Expect to use quite high number: 80-100 % for enough torque at 4-5 v.
    * Removed a couple of defines that were not used.
    * Docementation on how to build separate tests in platformio. First version.
    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
    [motor.cpp]
2025-02-10 Unsensor (#26)
    * First structure for the config package
    * Higly improved Usensor, both the component test that shows both distance and age. And the comments and structure in the usensor class has been improved, especially around the POLL_INTERVAL
    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
    [config.cpp, usensor.cpp]
2025-02-16 Cleaned up and restructured a bit, preparing for different chassi-typesusing the same electronics
    [atmt.brd, atmt.sch, body-top-7.stl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]
2025-02-22 New PCB version, HW 3.2
    [atmt-kcad.kicad_pcb]
2025-03-01 Accsensor added and tested (#28)
    * updated platformio.ini
    * Updated and tested usensor in accordance with the new directory structure
    * Added accsensor and all uodates required for that. It could be that the change of setget to long instead of int coaul case some issues with other packets, needs to be verified. maybe overlaying so that both exists?
    * Seems I missed these two for my accsensor commit.
    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
    [accsensor.cpp, config.cpp]
2025-03-06 More to pull (#29)
    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
2025-03-08 First shot of kalman-filter for acc
    [table-stand.FCStd, table-stand.stl]
2025-03-09 New steer, which lead to other modifications and improvements.... (#30)
    * Mainly recreation of steer, but some other updates were also required.
    * Accsensorcalibration added
    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
2025-03-09 Updated needed files to support so that steer.direction stores the latest steering number in the globalVar steerDirection. This is so that motor:drive can read and use this information if differentia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
2025-03-09 z_main_steer_test file which initiates the setget before it is used by steer.
2025-03-09 Corrected the PWM channel since the motor package need booth ch0 and ch 1 when using differential steering.
    [steer.cpp]
2025-03-09 Added support for the normal motor instead of a servo for steering.
2025-03-09 added so that both proportional sterring as well as the original digital steering is tested.
2025-03-10 Uppdates ragerding steering, should now support ordinary motor and not only servo (#31)
    * Updated needed files to support so that steer.direction stores the latest steering number in the globalVar steerDirection. This is so that motor:drive can read and use this information if differential steering is enabled. >This is yet to be implemented
    * z_main_steer_test file which initiates the setget before it is used by steer.
    * Corrected the PWM channel since the motor package need booth ch0 and ch 1 when using differential steering.
    * Added support for the normal motor instead of a servo for steering.
    * added so that both proportional sterring as well as the original digital steering is tested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
    [steer.cpp]
2025-03-10 Bugfixes in steer.h When using MOTOR instead of servo the PWM was no t initialised, now adjusted. Still not tested for MOTOR
    [steer.cpp]
2025-03-11 added missing ref to config.cpp for env:motor
2025-03-17 driver started
2025-03-17 differential basic support added to motor
2025-03-17 simple i2c scanner to find unknown addresses
2025-03-18 corrected default config to be SINGLE motor and MOTOR steering.
    [config.cpp]
2025-03-18 Minor fixes to get motor and steer to build agan. Had to remove strange lib dependency I dfo not have and packages do not need. In steer the use of the calculated variables and the correct calls to l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
    [steer.cpp]
2025-03-20 Added ESP32 ID of JCA01 to config file
2025-03-20 Sensor-values in structure, motor stops when clesd to obstacle
2025-03-20 Added remote bash client with new jeson format with 10 degrees precision for steering
2026-02-21 Add comprehensive .gitignore for embedded development project
    - PlatformIO build artifacts and IDE files
    - Python virtual environments and bytecode
    - KiCad backup and temporary files
    - FreeCAD backup files
    - OS and IDE temporary files
    - Security-sensitive files (secrets.h, config files)
2026-03-16 Before cleanup for ScaniaHack-2026
    [pyvenv.cfg]
2026-03-16 Rename: sw -> EmbeddedSw - Update VS Code configs and documentation
    [pyvenv.cfg]
2026-03-16 Huge restructure forScaniaHack 2026
    [atmt-kcad.csv, atmt-kcad.kicad_pcb, atmt-kcad.kicad_sch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]
2026-03-19 Changed the view of the map visualizer to plot every sensor separately
2026-03-19 Fixed crack/reboot and motorparameters
    [accsensor.cpp, compass.cpp, mqtt.cpp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]
2026-03-19 the magnetometer and accelerometer are working now
2026-03-19 fixed issue with linking calibration environment since task_safe_wire.cpp was not included
2026-04-27 Add configuration handling for vehicle types and database configuration
    - Implemented Config class in config.cpp to manage vehicle-specific settings based on device ID.
    - Added methods to retrieve motor type, steering type, and servo settings.
    - Created dbconfig.php for database connection parameters.
